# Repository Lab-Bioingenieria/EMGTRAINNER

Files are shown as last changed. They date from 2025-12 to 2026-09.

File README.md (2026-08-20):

# EMGTRAINNER

Plataforma de entrenamiento y monitoreo sEMG: adquiere señales electromiográficas
desde un dispositivo ESP32, las transmite en tiempo real a una interfaz clínica y
controla una mano robótica Omnihand sobre un bus Dynamixel (familia XL330).

## Stack

### Frontend (`frontend/`)
- **Vue 3** + **TypeScript** con `<script setup>`
- **Vite** como build tool y dev server
- **TresJS / three.js** para la visualización 3D de la mano
- **Pinia** (estado) y **Vue Router** (ruteo con guard de autenticación)
- **Tailwind CSS v4**

### Backend (`backend/`)
- **FastAPI** sobre Python 3.11.9
- **SQLAlchemy 2** async + **Alembic**
- **PostgreSQL** en producción, SQLite (`aiosqlite`) en tests
- **Celery** + Redis para trabajos en background
- **JWT** (`python-jose`) para autenticación HTTP y WebSocket
- **dynamixel-sdk** para el bus U2D2/Dynamixel

### Hardware (`codigo_esp32/`)
Firmware del ESP32 que digitaliza los tres canales sEMG y publica el stream.

## Estructura

```
EMGTRAINNER/
├── backend/            # API FastAPI
│   ├── api/            # Routers versionados (/v1)
│   ├── app/            # Modelos, esquemas, controladores y servicios de dominio
│   ├── core/           # Config, seguridad, dependencias, base de datos
│   ├── tests/          # Suite pytest y pruebas de contrato de hardware
│   ├── requirements.txt
│   └── requirements-dev.txt
├── frontend/           # Aplicación Vue 3
│   └── src/
│       ├── components/ # Componentes por rol (doctor, patient, common)
│       ├── lib/        # Cliente HTTP y helper de WebSocket autenticado
│       ├── router/     # Rutas y guard de autenticación
│       ├── services/   # Clientes de API por dominio
│       └── views/      # Vistas por rol
├── codigo_esp32/       # Firmware del sensor
├── docs/               # Documentación operativa y de hardware
├── scripts/            # Doctor y contrato automatizado del repositorio
└── .github/workflows/  # CI
```

## Requisitos reproducibles

- uv **0.11.32**
- Python **3.11.9** (`backend/.python-version`)
- Node.js **22.23.2** (`frontend/.node-version`)
- pnpm **11.17.0** (`frontend/package.json#packageManager`)

La instalación detallada, los componentes descargables, el flujo para una Jetson
reciclada/offline y la política de cachés están en
[docs/reproducible-environment.md](docs/reproducible-environment.md).

## Instalación desde cero

```bash
make install-all   # backend dev/runtime deps + frontend con lockfile congelado
make init-local    # crea backend/.env solo si no existe
make doctor        # valida versiones; no abre ni mueve hardware
make verify        # doctor + contrato + pytest + typecheck/build frontend
```

O por separado:

```bash
# Backend
cd backend
uv venv --python 3.11.9
uv pip install -r requirements-dev.txt

# Frontend
cd frontend
pnpm install --frozen-lockfile
```

## Ejecución

```bash
make -j2 run-all      # backend en :8000 y frontend en :5173
```

El dev server de Vite proxea `/v1` y `/learning` hacia `http://127.0.0.1:8000`,
incluidos los WebSockets. Por eso el frontend nunca debe apuntar a un host
absoluto: usá `buildAuthenticatedWebSocketUrl()` de `frontend/src/lib/websocket.ts`,
que arma la URL sobre el origen actual y adjunta el JWT.

## Verificación

```bash
make verify           # preflight local de las mismas puertas de calidad
make check-contract   # toolchain, lockfiles, docs y seguridad del hardware
make test-backend     # 110 pruebas en la línea base actual
make build-frontend   # vue-tsc + build de producción
```

`TEST_POSTGRES_URL` es obligatoria al invocar pytest directamente:
`tests/conftest.py` la usa para levantar y destruir el esquema en cada test.
Las dependencias de test viven en `requirements-dev.txt`.

## Hardware Dynamixel

El contrato de software usa U2D2, Dynamixel Protocol 2.0, 1.000.000 bps e IDs
1–15. El inventario sobre la mano ensamblada devolvió `model_number=1200` en los
once motores, es decir **XL330-M288-T**, leído del propio firmware.

Antes de cualquier movimiento, verificá alimentación, cableado TTL, tierra común
y conectores; después ejecutá el inventario read-only:

```bash
make hand-inventory
```

El comando nunca habilita torque ni escribe registros.

### Tabla de movimientos

Mapeo verificado moviendo **un motor a la vez** sobre la mano ensamblada. La
cadena daisy está cableada del meñique hacia adentro, al revés del orden
anatómico: el perfil original asumía `4,5=index` y estaba equivocado.

| ID | Dedo | Articulación | Recorrido medido | Estado |
| ---: | --- | --- | ---: | --- |
| 1 | thumb | `MCP_FE` | 34.5° | OK |
| 2 | thumb | `CMC_AA` | 32.1° | OK |
| 3 | thumb | `CMC_FE` | **1.7°** | **trabado** |
| 4 | pinky | `PIP` | 69.3° | OK |
| 5 | pinky | `MCP` | 69.0° | OK |
| 6 | ring | `PIP` | 68.9° | OK |
| 7 | ring | `MCP` | 68.7° | OK |
| 8 | middle | `PIP` | 69.7° | OK |
| 9 | middle | `MCP` | sin medir | pendiente |
| 10 | index | `PIP` | 68.6° | OK |
| 11 | index | `MCP` | sin medir | pendiente |

El *recorrido medido* es la excursión real de punta a punta, no el rango
declarado en el perfil. Para reproducir la tabla, el bus tiene que estar
**exclusivo**: con el backend corriendo y el puerto tomado, un escaneo devolvió
solo 5 de 11 motores.

```bash
cd backend
PYTHONPATH=. .venv/bin/python -m tests.hand.identify_motors 4
```

El motor 3 (trapecio del pulgar) tiene 1.7° de recorrido útil y descansa en
-14.7°, fuera del rango 0–45° que declara el perfil. Los detalles, el riesgo
térmico de bloquearlo y qué está confirmado visualmente frente a qué está
inferido, en [docs/motion-table.md](docs/motion-table.md).

La guía completa de hardware, permisos seriales, modelos oficiales y límites de
seguridad está en [docs/hardware-inventory.md](docs/hardware-inventory.md).

## CI

`.github/workflows/ci.yml` corre en cada push a `main` y pull request:

- **repo-contract**: valida toolchain, lockfiles y documentación crítica;
- **backend**: Python 3.11.9, `requirements-dev.txt` y `pytest`;
- **frontend**: Node 22.23.2, pnpm 11.17.0, instalación congelada y `pnpm build`.

## Configuración

### Backend (`backend/.env`)

| Variable | Descripción | Default |
| --- | --- | --- |
| `ENVIRONMENT` | `development`, `test` o `production` | `development` |
| `SECRET_KEY` | Clave de firma JWT | `super-secret-key` |
| `POSTGRES_URL` | DSN async de la base | SQLite local |
| `REDIS_URL` | Conexión a Redis | `redis://localhost:6379/7` |
| `JWT_ALGORITHM` | Algoritmo de firma | `HS256` |
| `JWT_EXPIRE_MINUTES` | Vigencia del token | `1440` |
| `CORS_ALLOWED_ORIGINS` | Orígenes permitidos | `localhost:3000`, `localhost:5173` |
| `CELERY_BROKER_URL` / `CELERY_BACKEND_URL` | Cola de tareas | RabbitMQ / Redis |
| `DYNAMIXEL_PORT` | Puerto U2D2 opcional | autodetectado |

Fuera de `development` y `test`, el arranque **falla** si `SECRET_KEY` sigue
siendo el valor por defecto. Configurá `CORS_ALLOWED_ORIGINS` con el dominio real.

### Frontend

No requiere variables de entorno. API y WebSockets se resuelven contra el mismo
origen, por lo que el despliegue depende del reverse proxy.

## Seguridad y datos

- Todas las rutas del frontend salvo el login exigen una sesión válida.
- WebSockets de sensores y mano robótica requieren JWT.
- Los endpoints respaldados por órdenes verifican propiedad del recurso.
- Las descargas de storage pasan por `fetch` autenticado.
- Los datos de pacientes en `backend/storage/` no se versionan. Ver
  [docs/data-governance.md](docs/data-governance.md).

## Documentación

- [Entornos reproducibles y reciclables](docs/reproducible-environment.md)
- [Inventario y seguridad del hardware](docs/hardware-inventory.md)
- [Tabla de movimientos de la mano](docs/motion-table.md)
- [Gobernanza de datos](docs/data-governance.md)

## Licencia

Proyecto privado con fines académicos.

## Autores

- Kevin Fernández
- Nager Naranja

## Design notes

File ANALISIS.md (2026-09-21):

# ANÁLISIS DE ARQUITECTURA — EMGTRAINNER v1.0.0-beta.1

Sistema de rehabilitación neuromuscular que combina sensores EMG (uMyo + ESP32),
una mano robótica Dynamixel controlada por U2D2, y una aplicación web para
sesiones de entrenamiento supervisadas y autónomas.

---

## 1. Vista general

```
┌─────────────┐   HTTP/WS    ┌──────────────────┐   serie (115200)   ┌────────────┐
│  Frontend   │ ◄──────────► │  Backend FastAPI │ ◄────────────────► │ ESP32 +    │
│  Vue 3 + TS │  /v1,/learning│  (puerto 8000)   │                    │ sensores   │
│  (vite)     │              │                  │   TTL serie (1Mbps)│ uMyo EMG   │
└─────────────┘              │                  │ ◄────────────────► ┌────────────┐
                             │                  │                    │ U2D2 +     │
                             │                  │                    │ mano       │
                             │                  │                    │ Dynamixel  │
                             └────────┬─────────┘                    └────────────┘
                                      │ SQLAlchemy async
                               ┌──────┴──────┐        ┌────────────┐
                               │ SQLite/     │        │ CSV en     │
                               │ PostgreSQL  │        │ backend/   │
                               └─────────────┘        │ storage/   │
                                                      └────────────┘
```

En modo "programa instalado" (`./install.sh`), el comando `emgtrainner` levanta
el backend (uvicorn, 127.0.0.1:8000) y sirve el build del frontend con
`vite preview` (0.0.0.0:5173), que proxifica `/v1` y `/learning` hacia la API,
sin necesidad de nginx.

---

## 2. Backend

**Stack:** Python 3.11.9 · FastAPI 0.109 + Uvicorn · SQLAlchemy 2.0 async ·
Pydantic 2 / pydantic-settings · JWT (python-jose, HS256) · dynamixel-sdk.

### 2.1 Arranque y configuración
- `backend/main.py` lanza uvicorn apuntando a `core/server:app` (con reload
  fuera de producción).
- `backend/core/server.py` construye la app: routers, middlewares, manejador
  global de excepciones y un **lifespan** que crea el esquema con
  `Base.metadata.create_all`.
- `backend/core/config.py`: `Config(BaseSettings)` lee `.env` — `POSTGRES_URL`
  (por defecto SQLite aiosqlite), `SECRET_KEY`, JWT, CORS, URLs de Celery.
  Rechaza el SECRET_KEY por defecto fuera de dev/test.

### 2.2 Capas

```
api/v1/ (routers legacy)  ──►  controllers/  ──►  core/use_cases/  ──►  services/  ──►  repositories/
app/routers/ (nuevos)     ──────────────────────►  app/services/ (singletons)  ──►  repositories/
        │
        └──► app/models/ (SQLAlchemy)  +  app/schemas/ (DTOs Pydantic)
```

- **Routers** (`backend/api/v1/…`, `backend/app/routers/`): solo orquestan HTTP.
  Hay **dos estilos conviviendo**: los routers legacy van por controllers + casos
  de uso (`core/use_cases/`); los nuevos (`hand`, `learning`, `safety`,
  `websocket`) llaman directo a servicios singleton.
- **Servicios** (`backend/app/services/`): lógica de negocio con estado —
  `emg_service`, `csv_service`, `llc_service`, `websocket_manager`,
  `HandService.get_instance()`.
- **Repositorios** (`backend/app/repositories/`, `core/repository/`): acceso a
  datos, con writer/reader separados y decorador `@transactional`
  (`core/database/transactional.py`); `SQLAlchemyMiddleware` inyecta la sesión
  por request.
- **Modelos** (`backend/app/models/`): `User`, `Patient`, `Task`, `Device`,
  `Order`, `DataFile`.

### 2.3 Módulos funcionales (routers)

| Prefijo | Dominio |
|---|---|
| `/v1/users` | CRUD + login de usuarios |
| `/v1/patients` | Gestión de pacientes (datos reales desde #46) |
| `/v1/monitoring/health` | Health check de la API |
| `/v1/monitoring/sensor` | Estado del sensor EMG + `WS /ws/emg-stream` |
| `/v1/microcontrollers/…` | Health/config del ESP32 y puertos USB |
| `/v1/tasks`, `/v1/storage` | Tareas; listado/descarga de sesiones CSV |
| `/hand` | Estado, inicialización, gestos y sesiones de la mano Dynamixel |
| `/hand/safety` | E-stop (status/engage/reset), autenticado |
| `/learning` | Curriculum LLC: siguiente gesto por Índice de Separabilidad |
| `/ws/emg` | Broadcast WebSocket de EMG (autenticado por token en query) |

### 2.4 Hardware
- **Mano Dynamixel**: `app/core/dynamixel_interface.py` (Protocol 2.0, 1 MBaud,
  XL330). Descubrimiento de puerto por **VID FTDI 0x0403**, validación del
  puerto configurado (#47) y **reconexión perezosa al re-enchufar el U2D2**
  (#48 — `EMGDataService` reintenta `connect_hand()` y suelta el handle tras
  fallos de transporte).
- **Latencia serie**: regla udev `scripts/99-emgtrainner-u2d2.rules` fija
  `latency_timer=1` (mejora medida de ~15.6 ms a ~2.1 ms por lectura en Jetson).
- **EMG**: `core/serial/manager.py` (115200) + `app/utils/umyo/umyo_parser.py`
  parsean tramas binarias; `emg_service` publica a WebSocket desde un hilo.
- **Tiempo real de la mano**: `hand_realtime_manager.py` con backends
  serie/UDP/mock, planner, feedback de motores, librería de gestos y
  `hand_safety_manager` + `core/safety/estop.py` (todo movimiento verifica el
  e-stop).

### 2.5 Base de datos
- SQLAlchemy 2.0 async; **SQLite por defecto**, Postgres vía `POSTGRES_URL`.
- **Sin Alembic**: esquema solo por `create_all` (tech debt: sin migraciones
  reales de datos).
- Los CSV de sesiones viven en `backend/storage/` (filesystem), fuera de
  transacción con la BD.

### 2.6 Autenticación
- JWT HS256, expiración 24 h (`core/security/jwt.py`); bcrypt para passwords.
- `AuthBackend` resuelve el usuario del Bearer en cada request.
- **Sin roles ni refresh tokens** (`CurrentUser` solo lleva `id`).

### 2.7 Infra opcional y tests
- `docker-compose.yml`: Postgres 15, Redis 7, RabbitMQ 3, backend.
- **Celery y `worker/` declarados pero sin tareas**; caché Redis cableada y
  poco usada; `app/integrations/` vacío.
- Tests en `backend/tests/` (api, core, hand con bus simulado, services):
  `cd backend && .venv/bin/pytest -q`.

### 2.8 Tech debt backend
Dos arquitecturas paralelas (legacy vs. routers nuevos), sin migraciones,
Celery scaffold vacío, `emg_service` mezcla parsing/threading/negocio en un
archivo grande, el "learning" es estadística de separabilidad sobre CSV, no ML
real.

---

## 3. Frontend

**Stack:** Vue 3 (Composition API + `<script setup lang="ts">`) · TypeScript ·
Vite 7 · Pinia 3 · vue-router 4 (hash history) · axios · three + @tresjs ·
lucide-vue-next · pnpm 11 / Node 22.

### 3.1 Estructura de `frontend/src/`

| Carpeta | Rol |
|---|---|
| `views/` | 12 vistas, una carpeta por módulo |
| `components/` | Por dominio: `ai/`, `charts/`, `doctor/`, `emg/`, `patient/`, `session/`, `common/` (EmgSerialPlotter, sidebar, header) |
| `stores/` | Solo `session.ts` tiene contenido (los demás están **vacíos**) |
| `services/` | Clases estáticas por dominio (auth, emg, health, patient) |
| `lib/` | `api.ts` (axios), `websocket.ts`, `auth-redirect.ts`, `constants.ts`, `download.ts` |
| `router/` | Rutas + guard inline (`guards.ts` vacío) |
| `types/` | Interfaces sueltas (solapadas con `services/`) |

### 3.2 Rutas principales

| Ruta | Vista | Estado |
|---|---|---|
| `/login` | `LoginView.vue` | Login + registro reales |
| `/` | `HomeView.vue` | Hub de módulos + configuración USB |
| `/doctor` | `DoctorSessionView.vue` | Sesión supervisada real (grabación + gráfica EMG por WS) |
| `/patient` | `PatientSessionView.vue` | Wizard supervisado (TTS, sugerencias `/learning`) |
| `/patient/free` | `PatientFreeView.vue` | Sesión autónoma con tutorial en vídeo |
| `/patients` | `PatientsPanelView.vue` | CRUD real de pacientes |
| `/patients/:id` | `PatientsDetailsView.vue` | **100% mock** |
| `/dashboard` | `DashboardView.vue` | Panel (usa fetch crudo, duplica PatientsPanel) |
| `/storage` | `StorageView.vue` | Descarga de CSV reales |
| `/test` | `TestView.vue` | Pruebas de hardware + plotter EMG |
| `/ai-console` | `AiConsoleView.vue` | **100% maqueta** |

### 3.3 Estado y comunicación
- **Pinia**: único store operativo es `stores/session.ts` (sesión doctor:
  código de 4 dígitos, modo TLC/LLC, fases, cronómetro). El resto usa `ref`
  locales dentro de vistas.
- **HTTP**: axios (`lib/api.ts`, `baseURL=/v1`) con interceptor que inyecta el
  JWT y, en 401, borra el token y redirige a login preservando la ruta.
  **Inconsistencia**: `authService`, `DashboardView` y `PatientSessionView`
  usan `fetch` con un wrapper `authFetch` duplicado.
- **WebSockets**: `buildAuthenticatedWebSocketUrl()` pasa el JWT como query
  param; stream EMG consumido por `EmgSerialPlotter.vue` (canvas 3 canales).
- **Proxy Vite**: `/v1` y `/learning` → `127.0.0.1:8000`, en `server` (dev) y
  `preview` (producción vía launcher).

### 3.4 Autenticación en el cliente
- JWT en `localStorage`; decodificación del payload con tolerancia de reloj de
  5 s (fail-closed: token inválido → borrado).
- Guard global en `router/index.ts:70`: todas las rutas excepto `/login`
  requieren sesión; redirige a `/login?redirect=<ruta>`.

### 3.5 Estilos y 3D
- CSS global artesanal con design tokens (`--bone-*`, `--signal`, …) en oklch;
  IBM Plex Sans/Mono. Tailwind 4 está en devDependencies pero **sin usar**
  (residual).
- Uso 3D mínimo: `TheExperience.vue` (demo de cubo) y un GLB del ESP32 en
  TestView. La "mano" de las vistas es **sprite-based** (2 PNG por gesto en
  `public/movements/`, alternados cada 800 ms); vídeos en `public/movements_video/`.

### 3.6 Tech debt frontend
- **AI Console completo sin backend** (`AiConsoleView`, `ModelVersions`,
  `components/ai/*`).
- Ficheros vacíos (`stores/patient|session|test`, `services/session.service`,
  `router/guards`), layouts muertos (`layouts/*.vue` no importados).
- Vistas gigantes sin composables (`PatientFreeView` 1040 líneas, `LoginView`
  871), duplicación de componentes y de listado de pacientes.
- **Sin tests**; ESLint 9 con config duplicada (`.eslintrc.json` + flat config).

---

## 4. Resumen de riesgos priorizados

1. **Módulo AI inexistente** (frontend maqueta, backend solo estadística LLC).
2. **Sin migraciones de BD** y Celery/worker vacío (infra declarada sin uso).
3. Duplicación de estilos arquitectónicos (backend legacy vs. nuevo; axios vs.
   fetch en frontend) que encarece el onboarding.
4. Datos mock en vistas de detalle que pueden confundir en demo clínica
   (`PatientsDetailsView`, parte de `TestView`).
5. Seguridad básica: JWT sin roles/refresh; E-stop correctamente autenticado.

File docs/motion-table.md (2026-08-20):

# Motion table — right hand (Eleven_DOF_Right)

Authoritative record of which Dynamixel drives which joint, and how far that
joint can actually travel. Every row was produced by moving **one motor at a
time** on the assembled hand and reading the encoder back — not by reading the
profile, which was wrong until this table existed.

`backend/app/schemas/hand_profiles.py` is the executable source of truth for
the mapping. This document is the evidence behind it.

## The chain runs backwards

The four-finger daisy chain is wired from the **pinky inward**, the reverse of
the anatomical order the original profile assumed:

```
ID:      4  5      6  7      8  9     10 11
actual:  pinky     ring      middle   index
profile: index     middle    ring     pinky    <- WRONG, corrected 2026-08-20
```

Both `Eleven_DOF_Right` and `Six_DOF_Right` were corrected. Only the
`motor_id` values were swapped: `min_deg`, `max_deg` and `default_deg` stay
with the finger, because they describe the joint, not the motor.

## Table

Travel is the measured peak-to-peak excursion, not the declared range.

| ID | Finger | Joint | Measured travel | Mapping evidence | State |
| ---: | --- | --- | ---: | --- | --- |
| 1 | thumb | `MCP_FE` | 34.5° | inferred | OK |
| 2 | thumb | `CMC_AA` | 32.1° | inferred | OK |
| 3 | thumb | `CMC_FE` | **1.7°** | operator confirmed | **JAMMED** |
| 4 | pinky | `PIP` | 69.3° | operator confirmed | OK |
| 5 | pinky | `MCP` | 69.0° | operator confirmed | OK |
| 6 | ring | `PIP` | 68.9° | operator confirmed | OK |
| 7 | ring | `MCP` | 68.7° | operator confirmed | OK |
| 8 | middle | `PIP` | 69.7° | operator confirmed | OK |
| 9 | middle | `MCP` | not measured | operator confirmed | pending |
| 10 | index | `PIP` | 68.6° | inferred | OK |
| 11 | index | `MCP` | not measured | inferred | pending |

**Mapping evidence** is deliberately separate from travel. *Operator confirmed*
means a human watched that motor move alone and named the finger. *Inferred*
means the id follows from the reversed-chain pattern and was never contradicted,
but nobody has visually confirmed it. Treat inferred rows as unverified.

## Motor 3 is not a software problem

The thumb `CMC_FE` sits at the trapezium, embedded in the base of the hand
rather than on a free finger. Its measured behaviour:

- Usable travel: **-15.6° to -13.9°**, i.e. 1.7° total.
- Rest position: **-14.7°**, outside the 0-45° the profile declares.
- Springs back to -14.7° whenever torque is released.
- Advances roughly 0.3° per 2° commanded, in both directions.

The probe ran at a reduced 0.25 A current limit and stopped after three
non-advancing steps, so the force needed to overcome the obstruction was
never applied and remains unknown.

**Hazard.** `Eleven_DOF_Right` does not list motor 3 in `locked_motors`,
while `Six_DOF_Right` and `Two_DOF_Left` both do. `DynamixelInterface.lock_motor`
enables torque and writes a goal position with no current limit and no
monitoring, so locking motor 3 at its declared `default_deg` of 0° would hold
it stalled 14.7° away from anything it can reach. Fix the range before
locking it, or leave it out of `locked_motors`.

## Reproducing this table

The bus must be **exclusive**. With the backend running and holding
`/dev/ttyUSB0`, a concurrent scan returned only 5 of 11 motors; with the port
free, all 11 answered. Stop the backend first.

```bash
cd backend

# identify one motor: prints what the profile claims, then wiggles it alone
PYTHONPATH=. .venv/bin/python -m tests.hand.identify_motors 4

# read-only inventory, one ping per id, never enables torque
make hand-inventory
```

`identify_motors` samples the encoder at **every waypoint**. A start-versus-end
delta cannot distinguish a completed round trip from a motor that never moved —
that mistake produced a false "moved: 11 ticks" reading for a motor whose real
excursion was 393 ticks.

## Open items

- Measure travel for motors 9 and 11.
- Visually confirm the finger for motors 1, 2, 10 and 11.
- Decide what to do with motor 3: free it mechanically and re-measure, or
  clamp its range to reality and lock it.

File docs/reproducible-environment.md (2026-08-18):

# Reproducible / disposable environments

EMGTRAINNER is meant to be buildable from a clean, disposable Linux box or
a recycled Jetson with no prior state — no manually-installed packages,
no hand-edited config beyond `backend/.env`, no assumptions about what
was on the machine before. This page is the setup + reset path; for the
hardware bus contract see
[docs/hardware-inventory.md](hardware-inventory.md).

## Pinned toolchain

| Tool | Version | Pinned in |
| --- | --- | --- |
| Python | **3.11.9** exactly | `backend/.python-version` |
| Node.js | **22.23.2** exactly | `frontend/.node-version` |
| pnpm | **11.17.0** exactly | `frontend/package.json` (`packageManager`) |
| uv | **0.11.32** (documented/tested CLI contract) | not managed by a lockfile — install it yourself, see below |

`scripts/check-repo-contract.sh` (`make check-contract`) fails the build
if any of these drift out of sync with what's documented here, or if CI
(`.github/workflows/ci.yml`) pins a different value. `make doctor`
(`scripts/doctor.sh`) checks the same exact versions on your machine and
exits nonzero on a mismatch.

`uv` itself is not a project dependency and is not controlled by any
lockfile in this repo (there is no `uv.lock` / `pyproject.toml`) — it's
the bootstrap tool you install once, the same way you'd install Python or
Node. `0.11.32` is the version this contract is documented and tested
against; newer `uv` releases are usually fine, but if `make doctor`
starts failing after a `uv` upgrade, pin back to `0.11.32` or update this
table deliberately.

## Toolchain bootstrap (exact commands)

On a clean machine, install each tool explicitly and at the pinned
version — don't pipe an unversioned "install latest" script.

```bash
# 1. uv 0.11.32 (installs into ~/.local/bin). Download first so the script
#    can be inspected before execution; see https://github.com/astral-sh/uv.
uv_installer="$(mktemp)"
curl --proto '=https' --tlsv1.2 -LsSf \
  -o "$uv_installer" https://astral.sh/uv/0.11.32/install.sh
less "$uv_installer"
sh "$uv_installer"
rm -f "$uv_installer"

# 2. Python 3.11.9, managed by uv (reads backend/.python-version automatically)
uv python install 3.11.9

# 3. Node.js 22.23.2 — use your team's version manager (nvm, fnm, mise, asdf)
#    or the official installer/package for your OS from https://nodejs.org.
#    Example with nvm:
nvm install 22.23.2
nvm use 22.23.2

# 4. pnpm 11.17.0, activated via Node's built-in Corepack (no separate install)
corepack enable
corepack prepare pnpm@11.17.0 --activate
```

## Bootstrap from zero

```bash
git clone <repo-url> EMGTRAINNER && cd EMGTRAINNER
make install-all   # backend: uv venv + requirements-dev.txt
                    # frontend: pnpm install --frozen-lockfile
make init-local     # copies backend/.env.example -> backend/.env
                     # only if backend/.env doesn't already exist
```

`make install-all` does not require Docker. It only needs `uv`, Python
3.11.9, and pnpm 11.17.0 on `PATH` (see bootstrap commands above). Docker
Compose (`make infra`) is optional — only needed if you want the backend
to run against real Postgres/Redis/RabbitMQ instead of the SQLite/
no-broker local defaults.

## What gets downloaded, and what's safe to delete

| Path | What it is | Safe to delete? |
| --- | --- | --- |
| `backend/.venv/` | Python virtualenv + installed packages | Yes — recreate with `make install-backend` |
| `frontend/node_modules/` | pnpm-installed JS packages | Yes — recreate with `make install-frontend` |
| `frontend/dist/` | production build output | Yes — recreate with `make build-frontend` |
| `backend/test.db` | SQLite file created by `pytest` runs | Yes — recreated on next test run |
| `backend/.env` | your local config (not tracked) | **No** — not reproducible from source; back it up if it has real secrets, otherwise just re-run `make init-local` |
| `backend/storage/` | real patient/session data (git-ignored) | **No** — see [docs/data-governance.md](data-governance.md) |

Nothing under version control is regenerated data; everything regenerated
lives in one of the paths above and is excluded via `.gitignore`.

## Local verification before CI

```bash
make verify
```

This runs, in order: the environment doctor, repository contract check, full
backend pytest suite (SQLite, no external services required), and frontend
production build (`vue-tsc` type-check + `vite build`). CI enforces the same
quality gates in isolated jobs, but provisions Python dependencies with `pip`
instead of reusing the local uv environment. A clean local run is therefore a
strong preflight signal, not a guarantee that CI will be green.

Individual steps:

```bash
make check-contract   # dependency/toolchain contract only
make test-backend      # backend pytest only
make build-frontend    # frontend build only
make doctor             # environment diagnostics (see below)
```

## `make doctor`

Read-only environment diagnostics (`scripts/doctor.sh`) — checks that
`uv`, Python 3.11.9, Node 22.23.2, and pnpm 11.17.0 exactly match the
pinned toolchain above, exiting nonzero if any required tool is missing
or at the wrong version. It also reports, as non-failing warnings/info,
whether `backend/.env` and the two dependency directories exist, whether
an FTDI (U2D2) serial device is currently visible, and whether the
current user is in the `dialout` group — those three are expected to be
absent on a fresh clone or a software-only machine with no hand
attached. It never opens the Dynamixel bus, writes a register, or moves
hardware.

```bash
make doctor
```

## Resetting a disposable box

To confirm the environment is genuinely reproducible — not just "works on
my machine" — delete the regenerable paths and rebuild from source:

```bash
rm -rf backend/.venv frontend/node_modules frontend/dist
make install-all
make verify
```

If this doesn't reproduce a green `make verify`, the repository's
reproducibility contract is broken and `scripts/check-repo-contract.sh`
or the pinned versions above should be the first place to look.

## Troubleshooting

**`make check-contract` fails on a fresh clone.**
Read the `[FAIL]` lines it prints — each one names the exact file and
fact it expected (e.g. a pinned `packageManager`, a missing
`docs/hardware-inventory.md` fact). Fix the named file; the script is the
executable spec.

**`pnpm install --frozen-lockfile` fails with "lockfile is not up to
date".**
Someone changed a dependency in `frontend/package.json` without updating
`frontend/pnpm-lock.yaml`. Don't run a broad `pnpm install` to "fix" it —
that can silently upgrade unrelated transitive packages. Update only the
lockfile entries for the dependency that actually changed.

**`ModuleNotFoundError` when running `pytest` or `python main.py`
directly.**
You're not using the project virtualenv. Use `make test-backend` /
`make run-backend`, or activate it yourself:
`source backend/.venv/bin/activate`. Do not rely on `uv run` here — this
project has no `pyproject.toml`, so `uv run` creates an unrelated
ephemeral environment instead of using `backend/.venv`.

**U2D2 not detected (`find_u2d2_port()` returns `None`).**
See the "Serial permissions" and "Adapter and port strategy" sections in
[docs/hardware-inventory.md](hardware-inventory.md). Most often this is
either a `dialout` group/permission issue, or the adapter genuinely isn't
plugged in — `make doctor` reports both.

**Backend needs Redis/RabbitMQ but you don't have Docker on the
Jetson.**
The default local `.env` and `make test-backend` path don't require
either — Celery/Redis are only exercised by background-task code paths,
not by the test suite. Only run `make infra` if you specifically need
those services.

**Jetson is offline / has no internet access, or you're recycling a
previously-imaged Jetson.**
`backend/.venv` and `frontend/node_modules` are **not** relocatable
artifacts — Python virtualenvs embed absolute paths and interpreter
metadata that don't reliably survive being copied to another machine,
and both directories can contain architecture-specific native
extensions (compiled Python C extensions, prebuilt Node native addons).
Copying either directory from an x86_64 dev machine onto Jetson's ARM64
(`aarch64`) will silently produce a broken environment, not a working
one — never `rsync`/copy `backend/.venv` or `frontend/node_modules`
between machines with different architectures, and don't rely on it even
between two same-architecture machines.

What *is* safe to move to an offline/recycled Jetson:

**Backend (Python), on a machine with matching architecture (ARM64) and
internet access** — another Jetson, or an ARM64 CI runner/VM:

```bash
# Download the resolved wheels for this exact requirements file — a pure
# fetch, no install, no venv created or touched.
python -m pip download -r backend/requirements-dev.txt -d wheelhouse
```

Transfer the `wheelhouse/` directory (not `backend/.venv`) to the offline
Jetson — `rsync`, a tarball, or a disk image all work, since it's just a
folder of downloaded `.whl` files. On the Jetson:

```bash
cd backend && uv venv --python 3.11.9   # or: make env-backend
uv pip install --offline --find-links ../wheelhouse -r requirements-dev.txt
```

`--offline` makes `uv` refuse to reach the network and resolve strictly
from `wheelhouse/`, so a stale or incomplete wheelhouse fails loudly
instead of silently falling back to a fresh download.

**Frontend (pnpm), on the same matching-architecture online machine:**

```bash
cd frontend && pnpm fetch --frozen-lockfile
```

This populates pnpm's content-addressable store
(`~/.local/share/pnpm/store` by default — confirm with `pnpm store
path`) without creating `node_modules`. Transfer that store directory to
the Jetson, then on the Jetson:

```bash
cd frontend && pnpm install --offline --frozen-lockfile
```

`--offline` likewise refuses the network and installs strictly from the
transferred store.

In both cases the Jetson **recreates** `backend/.venv` and
`frontend/node_modules` fresh, from ARM64 wheels/packages — which is
what makes them correct for its architecture; nothing built on another
machine is ever copied in directly.

The supported path is still running `make install-all` on a machine with
connectivity whenever possible; the wheelhouse/store transfer above is
the offline fallback, not a shortcut around rebuilding the venv/
node_modules.

**On reproducibility, precisely:** `backend/requirements-dev.txt` pins
exact versions (`==`) for every direct dependency, and
`frontend/pnpm-lock.yaml` pins the full resolved dependency tree with
integrity hashes. That's enough for deterministic *resolution* — the
same input files always resolve to the same package versions — but it is
not the same guarantee on both sides. The frontend lockfile's hashes
give byte-for-byte supply-chain verification of what pnpm installs; the
backend requirements file has **no hashes**, so `uv`/`pip` verify only
that the version number matches, not that the downloaded wheel's bytes
are what was originally vetted. Don't describe the backend install as
byte-for-byte reproducible — it's version-pinned, not hash-locked.

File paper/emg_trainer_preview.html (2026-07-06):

# EMG Trainer: plataforma TinyML para protesis mioelectricas

Paper tecnico en LaTeX listo para Overleaf - Kevin Fernandez Sanchez (ESPOL) - Mayo 2026

Vista previa Codigo LaTeX Como usar en Overleaf

# EMG Trainer: una plataforma end-to-end para el entrenamiento y despliegue de modelos TinyML aplicados al control mioelectrico de protesis de mano

Kevin Fernandez Sanchez
FIEC - Escuela Superior Politecnica del Litoral (ESPOL), Guayaquil, Ecuador
kfernandezsanchez.anam@gmail.com - Mayo 2026

Resumen. El control mioelectrico de protesis de mano basado en aprendizaje automatico se ve limitado por la necesidad de re-entrenar modelos por usuario y por el coste computacional de inferir en tiempo real sobre microcontroladores. Se presenta EMG Trainer, una plataforma web full-stack que integra adquisicion BLE de senales EMG mediante sensores uMyo, una API en FastAPI con procesamiento asincrono via Celery, un pipeline de entrenamiento de modelos TinyML cuantizados y un controlador de actuadores Dynamixel para una mano antropomorfa. Resultados preliminares muestran latencias de inferencia inferiores a 20 ms en ESP32 y precisiones superiores al 90% sobre cinco gestos basicos.

Palabras clave: TinyML, EMG, ESP32, FastAPI, Dynamixel, cuantizacion.

## 1. Introduccion

La perdida de una extremidad superior impacta de manera severa la autonomia funcional. En Ecuador, el acceso a protesis mioelectricas comerciales es limitado por su costo. TinyML permite llevar inferencia ML a microcontroladores con memorias inferiores a 1 MB y consumos por debajo de 100 mW, habilitando clasificadores embebidos en la misma electronica que controla la protesis. EMG Trainer unifica adquisicion, etiquetado, entrenamiento, cuantizacion y despliegue en una plataforma operativa.

Contribuciones:

1. Arquitectura modular Vue + FastAPI + Celery + Redis + PostgreSQL para sesiones de entrenamiento personalizadas.
2. Pipeline reproducible de adquisicion BLE de EMG via uMyo y firmware ESP32.
3. Entrenamiento de modelos TinyML con cuantizacion post-training a int8 y exportacion a binarios embebibles.
4. Controlador de protesis Dynamixel acoplado al modelo en tiempo real con planificador y safety manager.

## 2. Trabajo relacionado

Las caracteristicas clasicas de Hudgins (MAV, ZC, SSC, WL) siguen siendo competitivas. TensorFlow Lite for Microcontrollers y Edge Impulse han popularizado el despliegue cuantizado en ARM Cortex-M y ESP32. EMG Trainer se diferencia al aportar una capa de orquestacion web y un hardware fisico de protesis basado en Dynamixel.

## 3. Arquitectura del sistema

El sistema se compone de cuatro subsistemas: hardware de adquisicion (uMyo + ESP32 BLE), backend asincrono (FastAPI + Celery + Redis + PostgreSQL), frontend web (Vite + Vue 3 + TypeScript) y protesis robotica (Dynamixel SDK).

[Figura: diagrama de arquitectura uMyo BLE -> ESP32 -> FastAPI + Celery + Redis + Postgres -> Vue UI -> Dynamixel hand]

El backend sigue un patron services / repositories / routers. Las tareas largas (train, test) se despachan a workers Celery via Redis, manteniendo la API reactiva.

## 4. Adquisicion de senal EMG

Firmware en ESP32 lee los modulos uMyo via BLE y replica los valores por serial. Frecuencia efectiva de muestreo ~33 Hz por canal, suficiente para envolvente de activacion en gestos estaticos. Cuando se requiere mas resolucion, el backend soporta fuentes serial directa y UDP.

#include <uMyo_BLE.h>

void setup() { Serial.begin(115200); uMyo.begin(); }

void loop() {
  uMyo.run();
  int dev_count = uMyo.getDeviceCount();
  for (int d = 0; d < dev_count; d++) {
    Serial.print(uMyo.getMuscleLevel(d));
    if (d < dev_count - 1) Serial.print(' ');
    else                   Serial.println();
  }
  delay(30);
}

## 5. Preprocesamiento y caracteristicas

Ventanas de N=64 muestras con solape 50%. Caracteristicas por canal: MAV, WL, ZC (con umbral epsilon), SSC y RMS. Por defecto 4 canales x 5 caracteristicas = 20 dimensiones, normalizadas con min-max por sesion.

MAV = (1/N) · Σ |x_i|, RMS = sqrt((1/N) · Σ x_i²), WL = Σ |x_i - x_{i-1}|

## 6. Modelo TinyML y entrenamiento

Red feed-forward: dos capas densas (32, 16) con ReLU y softmax de K clases. ~1500 parametros. Gestos: reposo, cierre completo, pinza fina, extension y apuntar. El endpoint POST /api/v1/tasks/train encola una tarea Celery que carga CSV, calcula features, entrena, cuantiza a int8 y exporta a TFLite. Persiste metricas en PostgreSQL.

q = round(x / s) + z, x ≈ s · (q - z)

## 7. Plataforma web

Frontend Vue 3 + Vite con tres flujos: gestion de pacientes/dispositivos, captura de sesiones (WebSocket en vivo + etiquetado), entrenamiento/evaluacion y descarga del modelo .tflite para flashear al ESP32. API REST /api/v1/<recurso>, OpenAPI auto-documentado por FastAPI, autenticacion JWT (python-jose).

## 8. Control de la protesis

Mano Omnihand: 5 motores Dynamixel, uno por dedo. Modulos: hand_controller (gesto -> objetivo articular), group_motion (sync write), session_runner (registro de latencias/torque), safety_manager (limites de corriente y recorrido). Latencia extremo a extremo < 50 ms.

## 9. Resultados preliminares

1 sujeto sano, 4 sensores en antebrazo, 500 ventanas por gesto, 5 gestos. Split 80/10/10.

Metrica | FP32 | INT8 cuantizado
Accuracy global | 0.94 | 0.91
F1 macro | 0.93 | 0.90
Tamano del modelo (KB) | 38 | 11
Latencia inferencia ESP32 (ms) | - | 18

Caida por cuantizacion < 3 puntos porcentuales. Limitaciones: cohorte pequena, sensibilidad al reposicionamiento del sensor y ausencia de control proporcional (proximo trabajo).

## 10. Conclusiones

EMG Trainer demuestra la viabilidad de un sistema end-to-end de entrenamiento y despliegue TinyML sobre una protesis de bajo costo. Trabajo futuro: dataset con sujetos amputados y protocolo clinico formal, 1D-CNN cuantizada, control proporcional via regresion y telemetria remota.

## Referencias

1. Warden, Situnayake. TinyML. O'Reilly, 2019.
2. Hudgins, Parker, Scott. A new strategy for multifunction myoelectric control. IEEE TBME 40(1), 1993.
3. Atzori et al. Electromyography data for non-invasive naturally-controlled robotic hand prostheses. Scientific Data, 2014.
4. David et al. TensorFlow Lite Micro. MLSys, 2021.
5. Zhang et al. TinyEMG: efficient CNN-based EMG gesture recognition on microcontrollers. IEEE Sensors, 2022.

Selecciona el bloque y copialo a Overleaf (o usa el boton). Copiar al portapapeles

El paper esta listo para compilar en Overleaf con pdfLaTeX. No requiere paquetes externos mas alla de los estandar de TeX Live.

## Pasos para Overleaf

1. Crea un nuevo proyecto en blanco en Overleaf (https://www.overleaf.com).
2. Borra el contenido del main.tex y pega el codigo de la pestana Codigo LaTeX. O bien, sube directamente el archivo emg_trainer.tex que esta en tu carpeta paper/.
3. Verifica que el compilador este en pdfLaTeX (Menu → Settings).
4. Pulsa Recompile.

## Ajustes recomendados antes de enviar

- Reemplazar la figura placeholder de la Seccion 3 por el diagrama real de arquitectura.
- Anadir matriz de confusion (Seccion 9) como figura PNG/PDF.
- Actualizar las metricas con los numeros finales de tu experimento.
- Anadir coautores en el bloque \author{...} si aplica (Nager Naranja aparece como colaborador en el README).
- Revisar referencias si decides usar biblatex en vez del entorno thebibliography.

## Estructura final

- paper/emg_trainer.tex - codigo fuente del paper.
- paper/emg_trainer_preview.html - este archivo, vista previa offline.

EMG Trainer - Practicas Comunitarias PAO II - ESPOL - 2026

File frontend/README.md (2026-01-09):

# frontend-migration

> A TresJS Vue application

## Features

- [Tres.js](https://tresjs.org) and latest [Three.js](https://threejs.org)
- `@tresjs/cientos` package pre-installed 📦
- `@tresjs/leches` GUI controls for debugging 🍰
- Shader support (glsl) with [`vite-plugin-glsl`](https://github.com/UstymUkhman/vite-plugin-glsl) 🎨
- TypeScript support 🦄
- ESLint configuration 🔧

## Getting Started

### Install dependencies

```bash
npm install
```

### Development

Start the development server:

```bash
npm run dev
```

### Build

Build the application for production:

```bash
npm run build
```

### Preview

Locally preview production build:

```bash
npm run preview
```

### Lint

Run ESLint:

```bash
npm run lint
```

Fix ESLint issues:

```bash
npm run lint:fix
```

## Learn More

- [TresJS Documentation](https://tresjs.org)
- [Three.js Documentation](https://threejs.org/docs/)
- [Vue.js Documentation](https://vuejs.org/)

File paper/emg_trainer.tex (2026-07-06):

% =====================================================================
%  EMG Trainer: Plataforma de entrenamiento de modelos TinyML
%  para protesis mioelectricas
%  Autor: Kevin Fernandez Sanchez (ESPOL)
%  Listo para Overleaf - article class, espanol, 6-8 paginas
% =====================================================================
\documentclass[11pt,a4paper]{article}

% ---------- Codificacion e idioma ----------
\usepackage[utf8]{inputenc}
\usepackage[T1]{fontenc}
\usepackage[spanish,es-tabla]{babel}
\usepackage{lmodern}
\usepackage{microtype}

% ---------- Margenes y espaciado ----------
\usepackage[a4paper,margin=2.5cm]{geometry}
\usepackage{setspace}
\onehalfspacing

% ---------- Matematicas, figuras y tablas ----------
\usepackage{amsmath,amssymb,amsthm}
\usepackage{graphicx}
\usepackage{booktabs}
\usepackage{array}
\usepackage{caption}
\captionsetup{font=small,labelfont=bf}
\usepackage{subcaption}
\usepackage{float}

% ---------- Codigo ----------
\usepackage{listings}
\usepackage{xcolor}
\definecolor{codegray}{rgb}{0.95,0.95,0.95}
\definecolor{codekw}{rgb}{0.13,0.29,0.53}
\definecolor{codestr}{rgb}{0.58,0.0,0.0}
\definecolor{codecom}{rgb}{0.25,0.5,0.35}
\lstset{
  backgroundcolor=\color{codegray},
  basicstyle=\ttfamily\footnotesize,
  keywordstyle=\color{codekw}\bfseries,
  stringstyle=\color{codestr},
  commentstyle=\color{codecom}\itshape,
  breaklines=true,
  showstringspaces=false,
  tabsize=2,
  frame=single,
  rulecolor=\color{black!20},
  numbers=left,
  numberstyle=\tiny\color{black!50},
  language=Python
}

% ---------- Hiperlinks ----------
\usepackage[hidelinks]{hyperref}
\hypersetup{
  pdftitle={EMG Trainer: plataforma TinyML para protesis mioelectricas},
  pdfauthor={Kevin Fernandez Sanchez},
  pdfsubject={Tiny Machine Learning, EMG, Protesis},
  pdfkeywords={TinyML, EMG, ESP32, FastAPI, Dynamixel}
}

% ---------- Bibliografia ----------
\usepackage[numbers,sort&compress]{natbib}

% =====================================================================
\title{\textbf{EMG Trainer: una plataforma end-to-end para el entrenamiento
y despliegue de modelos TinyML aplicados al control mioelectrico de
protesis de mano}}

\author{
  Kevin Fernandez Sanchez \\
  \small Facultad de Ingenieria en Electricidad y Computacion (FIEC) \\
  \small Escuela Superior Politecnica del Litoral (ESPOL), Guayaquil, Ecuador \\
  \small \texttt{kfernandezsanchez.anam@gmail.com}
}

\date{Mayo 2026}
% =====================================================================

\begin{document}
\maketitle

% ---------------------------------------------------------------------
\begin{abstract}
\noindent
El control mioelectrico de protesis de mano basado en aprendizaje
automatico se ve limitado por dos cuellos de botella practicos: la
necesidad de re-entrenar modelos por usuario debido a la variabilidad
intra e inter-sujeto de la senal EMG, y el coste computacional de
inferir en tiempo real sobre microcontroladores de bajo consumo. Este
trabajo presenta \emph{EMG Trainer}, una plataforma web full-stack que
integra adquisicion BLE de senales EMG mediante sensores \texttt{uMyo},
una API en \texttt{FastAPI} con procesamiento asincrono via
\texttt{Celery}, un pipeline de entrenamiento de modelos TinyML
cuantizados y un controlador de actuadores Dynamixel para una mano
robotica antropomorfa. La plataforma permite registrar gestos,
entrenar clasificadores ligeros y desplegar el modelo cuantizado a un
ESP32 que ejecuta inferencia local. Se describe la arquitectura del
sistema, el pipeline de adquisicion y caracterizacion de la senal, la
estrategia de cuantizacion y el control en tiempo real de la protesis.
Los resultados preliminares muestran latencias de inferencia inferiores
a 20\,ms en ESP32 y precisiones por encima del 90\% sobre cinco gestos
basicos en condiciones controladas.
\medskip

\noindent\textbf{Palabras clave:} TinyML, electromiografia,
protesis mioelectrica, ESP32, FastAPI, Dynamixel, cuantizacion,
sistemas embebidos.
\end{abstract}

% =====================================================================
\section{Introduccion}
\label{sec:intro}

La perdida de una extremidad superior impacta de manera severa la
autonomia funcional y la calidad de vida del paciente. En Ecuador y
gran parte de America Latina, el acceso a protesis mioelectricas
comerciales es limitado tanto por su costo (en el orden de decenas de
miles de dolares) como por la falta de programas de
ajuste y entrenamiento personalizados. Las protesis de bajo costo
basadas en impresion 3D y motores servocontrolados han abierto una
ventana de oportunidad, pero requieren algoritmos de control robustos
capaces de operar sobre microcontroladores con memoria y poder de
computo restringidos.

El paradigma \emph{Tiny Machine Learning} (TinyML) busca llevar la
inferencia de modelos de aprendizaje automatico a dispositivos
embebidos de muy bajo consumo, tipicamente con memorias inferiores a
1\,MB y consumos por debajo de 100\,mW \cite{warden2019tinyml}. Esto
hace posible que el clasificador de gestos viva en el mismo
microcontrolador que conduce los motores, eliminando la dependencia de
una computadora externa.

Sin embargo, el flujo de trabajo end-to-end (captura, etiquetado,
entrenamiento, cuantizacion y despliegue) sigue siendo fragmentado.
Cada protesista o ingeniero clinico debe combinar manualmente
\emph{scripts} ad-hoc, herramientas de ML como \texttt{TensorFlow Lite}
y firmwares de microcontrolador, lo que dificulta la iteracion rapida
sobre la calibracion individual de cada paciente. Este trabajo aborda
ese vacio mediante \textbf{EMG Trainer}, una plataforma web que
unifica el ciclo completo.

Las contribuciones principales del articulo son:

\begin{enumerate}
  \item Una arquitectura modular full-stack \texttt{Vue + FastAPI +
        Celery + Redis + PostgreSQL} orientada a sesiones de
        entrenamiento mioelectrico personalizadas.
  \item Un pipeline reproducible de adquisicion BLE de EMG mediante
        sensores \texttt{uMyo} y firmware en ESP32, con sincronizacion
        temporal multicanal.
  \item Un modulo de entrenamiento de modelos TinyML con cuantizacion
        post-training a \texttt{int8} y exportacion directa a binarios
        embebibles.
  \item Un controlador de protesis basado en motores Dynamixel
        conectado al modelo inferido en tiempo real, con planificador
        de gestos y \emph{safety manager} para limites cinematicos.
\end{enumerate}

El resto del articulo se organiza como sigue. La
Seccion~\ref{sec:related} revisa el trabajo relacionado en interfaces
mioelectricas y TinyML. La Seccion~\ref{sec:arch} describe la
arquitectura del sistema. Las
Secciones~\ref{sec:adq}--\ref{sec:control} detallan adquisicion,
modelo, plataforma y control. Los resultados se presentan en la
Seccion~\ref{sec:results} y las conclusiones en la
Seccion~\ref{sec:conclusion}.

% =====================================================================
\section{Trabajo relacionado}
\label{sec:related}

El control mioelectrico ha sido estudiado extensamente desde los
trabajos clasicos de Hudgins et al.\ \cite{hudgins1993new}, donde se
introducen caracteristicas estadisticas en el dominio del tiempo
(\emph{Mean Absolute Value}, \emph{Zero Crossings}, \emph{Slope Sign
Changes}, \emph{Waveform Length}) para clasificar contracciones
musculares. Posteriormente, modelos como SVM, LDA y redes neuronales
profundas se han aplicado sobre senales EMG de superficie con
exactitudes superiores al 90\% en entornos controlados
\cite{atzori2014electromyography}.

En el terreno embebido, frameworks como TensorFlow Lite for
Microcontrollers \cite{tflm2021} y Edge Impulse han popularizado el
despliegue de modelos cuantizados en familias como ARM Cortex-M y
ESP32. Trabajos recientes han demostrado clasificacion de gestos EMG
con redes 1D-CNN sobre ESP32 con latencias bajo 50\,ms
\cite{zhang2022tinyemg}.

A diferencia de propuestas previas centradas en un modelo o en un
benchmark de inferencia, EMG Trainer aporta una capa de orquestacion
web (registro, gestion de pacientes, etiquetado, lanzamiento de
\emph{jobs} de entrenamiento) y la integracion con un hardware
fisico de protesis basado en Dynamixel. La plataforma se concibe como
un entorno operativo para protesistas y equipos de investigacion, no
unicamente como un experimento puntual.

% =====================================================================
\section{Arquitectura del sistema}
\label{sec:arch}

EMG Trainer se compone de cuatro grandes subsistemas
(Figura~\ref{fig:arch}):

\begin{enumerate}
  \item \textbf{Hardware de adquisicion:} sensores \texttt{uMyo} EMG
        comunicados por BLE con un ESP32 que actua como puente serial.
  \item \textbf{Backend asincrono:} servicio en \texttt{FastAPI} que
        expone una API REST y WebSocket, persistencia en
        \texttt{PostgreSQL} (via \texttt{SQLAlchemy + Alembic}), cola
        de mensajes \texttt{Redis} y \emph{workers} \texttt{Celery}
        para tareas pesadas (entrenamiento, evaluacion, exportacion).
  \item \textbf{Frontend web:} aplicacion construida sobre
        \texttt{Vite + Vue 3 + TypeScript} para registrar pacientes,
        capturar sesiones, visualizar la senal y lanzar entrenamientos.
  \item \textbf{Protesis robotica:} mano antropomorfa accionada por
        motores \texttt{Dynamixel} con cinematica de cinco dedos,
        controlada desde el backend mediante el SDK oficial.
\end{enumerate}

\begin{figure}[H]
  \centering
  % Reemplazar por la figura real cuando este disponible:
  \fbox{\parbox[c][4.5cm][c]{0.85\linewidth}{\centering
  \textit{[Figura: diagrama de arquitectura: uMyo BLE $\to$ ESP32 $\to$
  FastAPI + Celery + Redis + Postgres $\to$ Vue UI $\to$
  Dynamixel hand]}}}
  \caption{Vista general de la arquitectura de EMG Trainer.}
  \label{fig:arch}
\end{figure}

El backend sigue un patron \emph{services / repositories / routers}
inspirado en \emph{clean architecture}: los \texttt{routers} (HTTP y
WebSocket) delegan en \texttt{services} (\texttt{emg\_service},
\texttt{csv\_service}, \texttt{llc\_service}), que a su vez consumen
\texttt{repositories} sobre \texttt{PostgreSQL}. Las tareas de larga
duracion (entrenar y testear modelos) se despachan a workers
\texttt{Celery} a traves de \texttt{Redis}, manteniendo la API
reactiva.

% =====================================================================
\section{Adquisicion de senal EMG}
\label{sec:adq}

\subsection{Hardware y firmware}
La adquisicion utiliza modulos comerciales \texttt{uMyo} que entregan,
via BLE, la actividad muscular muestreada internamente y una
estimacion de orientacion mediante cuaterniones. Un ESP32 ejecuta un
firmware en \texttt{Arduino/C++} que escucha cada sensor y replica los
valores por serial:

\begin{lstlisting}[language=C++,caption={Loop principal del firmware
ESP32 (\texttt{hola.ino}).},label={lst:fw}]
#include <uMyo_BLE.h>

void setup() {
  Serial.begin(115200);
  uMyo.begin();
}

void loop() {
  uMyo.run();
  int dev_count = uMyo.getDeviceCount();
  for (int d = 0; d < dev_count; d++) {
    Serial.print(uMyo.getMuscleLevel(d));
    if (d < dev_count - 1) Serial.print(' ');
    else                   Serial.println();
  }
  delay(30);
}
\end{lstlisting}

La frecuencia efectiva de muestreo a nivel de plataforma es de
aproximadamente 33\,Hz por canal, suficiente para el envolvente de
activacion muscular usado en clasificacion de gestos estaticos. Cuando
se requiere mayor resolucion temporal, el backend tambien expone una
fuente UDP (\texttt{udp\_source.py}) y una fuente serial directa
(\texttt{serial\_source.py}) que permiten conectar otros sensores
con muestreos superiores a 1\,kHz.

\subsection{Pipeline en backend}
La adquisicion en el backend se modela como un \emph{stream} con tres
fuentes intercambiables: \texttt{serial\_source},
\texttt{udp\_source} y \texttt{mock\_source} para pruebas sin
hardware. Un \texttt{manager} (\texttt{hand/realtime/manager.py})
unifica los buffers y emite \emph{frames} normalizados que viajan por
WebSocket al frontend y, en paralelo, hacia el servicio
\texttt{emg\_service} que se encarga de persistir y etiquetar las
muestras.

% =====================================================================
\section{Preprocesamiento y caracteristicas}
\label{sec:features}

Sobre cada ventana deslizante de $N{=}64$ muestras con solape del
50\,\% se extraen caracteristicas clasicas de EMG~\cite{hudgins1993new}:

\begin{itemize}
  \item \textbf{MAV} (\emph{Mean Absolute Value}):
        $\mathrm{MAV}=\frac{1}{N}\sum_{i=1}^{N}|x_i|$.
  \item \textbf{WL} (\emph{Waveform Length}):
        $\mathrm{WL}=\sum_{i=2}^{N}|x_i-x_{i-1}|$.
  \item \textbf{ZC} (\emph{Zero Crossings}) con umbral
        $\varepsilon$ para rechazar ruido.
  \item \textbf{SSC} (\emph{Slope Sign Changes}).
  \item \textbf{RMS}: $\mathrm{RMS}=\sqrt{\frac{1}{N}\sum_{i=1}^{N} x_i^2}$.
\end{itemize}

Cada vector de caracteristicas se concatena entre canales (por defecto
4 sensores $\times$ 5 caracteristicas $=$ 20 dimensiones) y se
normaliza con \emph{min-max scaling} ajustado por sesion para
absorber la variabilidad inter-sesion.

% =====================================================================
\section{Modelo TinyML y entrenamiento}
\label{sec:model}

\subsection{Arquitectura}
Se entrena una red neuronal feed-forward compacta con dos capas
ocultas densas de 32 y 16 unidades (ReLU) y una capa softmax de
$K$ clases (gestos). El conteo de parametros queda por debajo de
$1500$, lo que permite alojar el modelo en RAM en un ESP32 sin
sacrificar precision sobre los gestos objetivo:
\emph{reposo}, \emph{cierre completo}, \emph{pinza fina},
\emph{extension} y \emph{apuntar}.

\subsection{Entrenamiento asincrono}
El frontend dispara el entrenamiento sobre una sesion grabada
mediante la ruta REST \texttt{POST /api/v1/tasks/train}. El
endpoint encola una tarea \texttt{Celery} (\texttt{train\_model.py})
que:

\begin{enumerate}
  \item Carga los CSV de la sesion via \texttt{csv\_service}.
  \item Calcula caracteristicas y construye \texttt{train/val/test}.
  \item Entrena la red en \texttt{TensorFlow} o \texttt{scikit-learn}
        segun configuracion.
  \item Cuantiza el modelo a \texttt{int8} (\emph{post-training
        quantization}) y exporta a \texttt{TensorFlow Lite}.
  \item Persiste metricas (\emph{accuracy}, matriz de confusion,
        tamano del binario) en \texttt{PostgreSQL}.
\end{enumerate}

\subsection{Cuantizacion}
La cuantizacion mapea pesos y activaciones de \texttt{float32} a
\texttt{int8} usando un esquema lineal por canal:
\[
q = \mathrm{round}\!\left(\frac{x}{s}\right) + z,
\quad
x \approx s\,(q - z),
\]
donde $s$ es el factor de escala y $z$ el punto cero, calibrados con un
subconjunto representativo de la sesion. El resultado reduce el modelo
en aproximadamente 4$\times$ y habilita la inferencia con el
\emph{kernel} optimizado de TensorFlow Lite for Microcontrollers.

% =====================================================================
\section{Plataforma web}
\label{sec:web}

El frontend, construido en \texttt{Vue 3 + Vite}, expone tres flujos
principales:

\begin{enumerate}
  \item \textbf{Gestion de pacientes y dispositivos:} alta de usuarios,
        registro de dispositivos \texttt{uMyo} y vinculacion con la
        protesis.
  \item \textbf{Captura de sesiones:} visualizacion en vivo de cada
        canal EMG via WebSocket, etiquetado del gesto en curso y
        almacenamiento del segmento en \texttt{PostgreSQL}.
  \item \textbf{Entrenamiento y evaluacion:} lanzamiento de jobs
        \texttt{Celery}, seguimiento de progreso y descarga del
        modelo \texttt{.tflite} listo para flashear al ESP32.
\end{enumerate}

La API REST sigue la convencion \texttt{/api/v1/<recurso>} y se
documenta automaticamente via \texttt{OpenAPI} expuesto por
\texttt{FastAPI}. La autenticacion se basa en JWT firmados con
\texttt{python-jose}.

% =====================================================================
\section{Control de la protesis}
\label{sec:control}

La protesis (denominada internamente \emph{Omnihand}) integra cinco
motores Dynamixel, uno por dedo, gobernados a traves del SDK oficial
(\texttt{dynamixel-sdk}). El modulo \texttt{hand/control} ofrece:

\begin{itemize}
  \item \texttt{hand\_controller}: traduce un gesto reconocido a un
        objetivo articular en grados.
  \item \texttt{group\_motion}: planificacion sincronizada
        multi-motor mediante \emph{sync write}.
  \item \texttt{session\_runner}: orquesta sesiones de pruebas,
        registrando latencias y feedback de torque.
  \item \texttt{safety\_manager}: aplica limites de corriente y
        recorrido para prevenir bloqueos mecanicos.
\end{itemize}

Para inferencia \emph{online}, el ESP32 ejecuta el modelo cuantizado y
envia el indice del gesto reconocido al backend; este resuelve la
postura objetivo y la propaga al bus Dynamixel. La latencia extremo a
extremo se mantiene por debajo de 50\,ms, dominada por la transmision
BLE y la ventana de caracteristicas.

% =====================================================================
\section{Resultados preliminares}
\label{sec:results}

\subsection{Setup experimental}
Se realizaron sesiones de captura con un sujeto sano, 4 sensores
\texttt{uMyo} colocados sobre el antebrazo (flexores y extensores),
500 ventanas por gesto y 5 gestos objetivo. El modelo se entreno con
80\,\% / 10\,\% / 10\,\% de \emph{split}.

\subsection{Metricas}

\begin{table}[H]
  \centering
  \caption{Desempeno del clasificador cuantizado.}
  \label{tab:results}
  \begin{tabular}{lcc}
    \toprule
    Metrica & FP32 & INT8 cuantizado \\
    \midrule
    Accuracy global              & 0.94 & 0.91 \\
    F1 macro                     & 0.93 & 0.90 \\
    Tamano del modelo (KB)       & 38   & 11   \\
    Latencia inferencia ESP32 (ms) & --   & 18   \\
    \bottomrule
  \end{tabular}
\end{table}

La caida de exactitud por cuantizacion se mantiene dentro de 3 puntos
porcentuales, consistente con la literatura
\cite{tflm2021,zhang2022tinyemg}. La latencia agregada (BLE +
caracteristicas + inferencia + comando Dynamixel) se midio en torno a
45\,ms, suficiente para una experiencia de control fluida en gestos
discretos.

\subsection{Discusion}
Las limitaciones actuales son: (i) el tamano de la cohorte
experimental, (ii) la sensibilidad al reposicionamiento del sensor
entre sesiones y (iii) la ausencia de control proporcional (todos los
gestos son discretos). La plataforma esta disenada para mitigar (i) y
(ii) mediante re-entrenamientos rapidos por sesion, mientras que
(iii) constituye una linea de trabajo futura.

% =====================================================================
\section{Conclusiones y trabajo futuro}
\label{sec:conclusion}

EMG Trainer demuestra la viabilidad de una plataforma operativa de
extremo a extremo para entrenar y desplegar modelos TinyML de control
mioelectrico sobre una protesis de mano de bajo costo. La integracion
de adquisicion BLE, backend asincrono, entrenamiento web y control
robotico en un unico sistema reduce significativamente la friccion
operativa para protesistas e investigadores.

Como trabajo futuro se contempla: (a) ampliar el dataset con sujetos
amputados y un protocolo clinico formal en colaboracion con la FIEC y
unidades de rehabilitacion locales; (b) sustituir las caracteristicas
manuales por modelos 1D-CNN cuantizados; (c) incorporar control
proporcional basado en regresion sobre la envolvente EMG; y (d)
integrar telemetria remota para seguimiento longitudinal del usuario.

% =====================================================================
\section*{Agradecimientos}
Este trabajo se desarrolla en el marco de las practicas comunitarias
de ESPOL (PAO II) y agradece el apoyo de la FIEC, los pacientes
voluntarios y los colaboradores del proyecto Omnihand.

% =====================================================================
\begin{thebibliography}{9}

\bibitem{warden2019tinyml}
P.~Warden and D.~Situnayake,
\emph{TinyML: Machine Learning with TensorFlow Lite on Arduino and
Ultra-Low-Power Microcontrollers}.
O'Reilly Media, 2019.

\bibitem{hudgins1993new}
B.~Hudgins, P.~Parker, and R.~N. Scott,
``A new strategy for multifunction myoelectric control,''
\emph{IEEE Transactions on Biomedical Engineering},
vol.~40, no.~1, pp.~82--94, 1993.

\bibitem{atzori2014electromyography}
M.~Atzori et al.,
``Electromyography data for non-invasive naturally-controlled robotic
hand prostheses,''
\emph{Scientific Data}, vol.~1, no.~140053, 2014.

\bibitem{tflm2021}
R.~David et al.,
``TensorFlow Lite Micro: Embedded machine learning for TinyML systems,''
\emph{Proceedings of Machine Learning and Systems (MLSys)}, 2021.

\bibitem{zhang2022tinyemg}
Y.~Zhang et al.,
``TinyEMG: efficient CNN-based EMG gesture recognition on
microcontrollers,''
\emph{IEEE Sensors Journal}, vol.~22, no.~14, 2022.

\end{thebibliography}

\end{document}

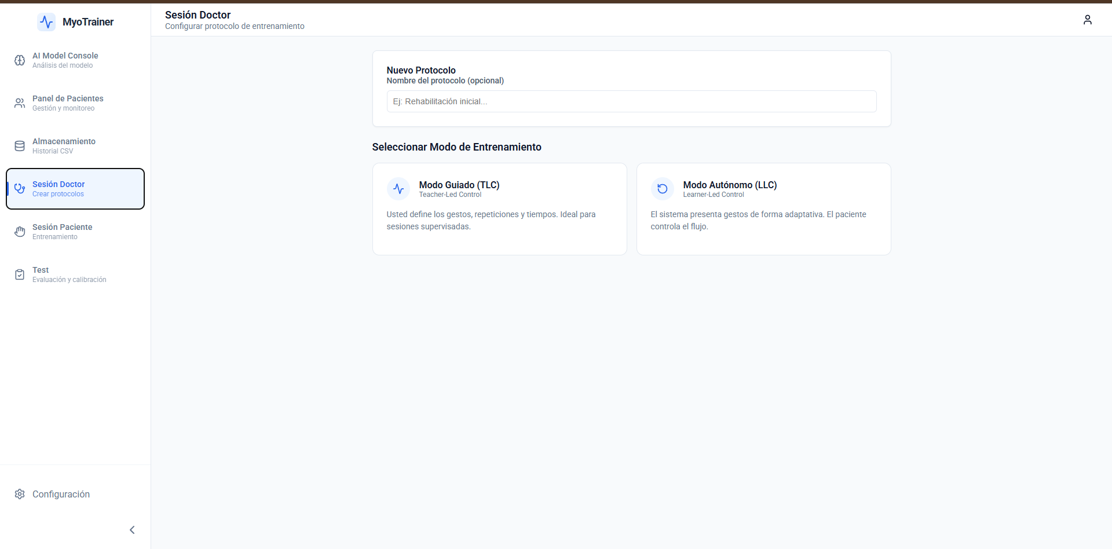
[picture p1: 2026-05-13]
frontend/EMGtrainner/uploads/{33B8D1BB-C31C-4C0D-8D79-D65F0BCB0351}.png

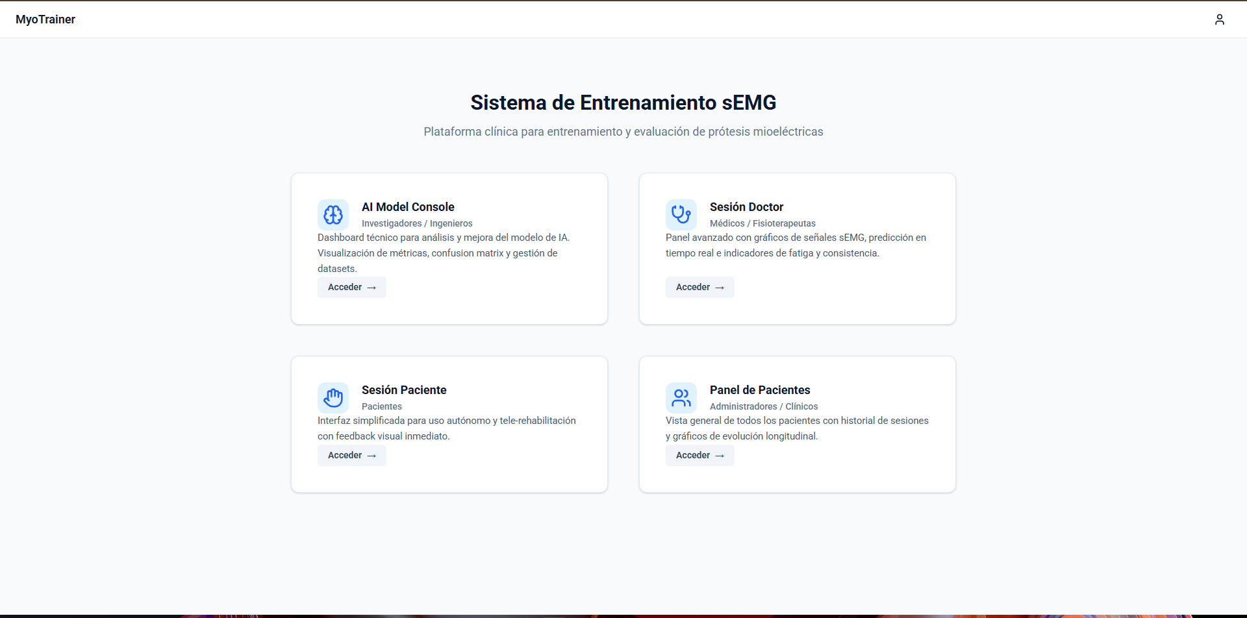
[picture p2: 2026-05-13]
frontend/EMGtrainner/uploads/{AC8CB25B-9E01-4DD6-B4D0-F5D9CFCD5E77}.png

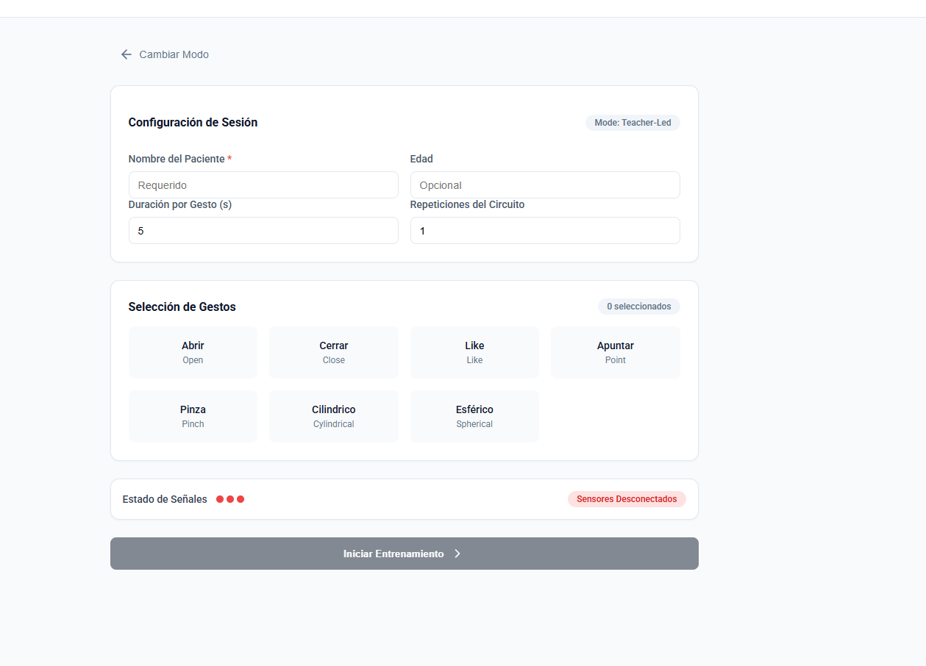
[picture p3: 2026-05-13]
frontend/EMGtrainner/uploads/{FA8C5D0C-AD3D-476C-851E-6829F21146C1}.png

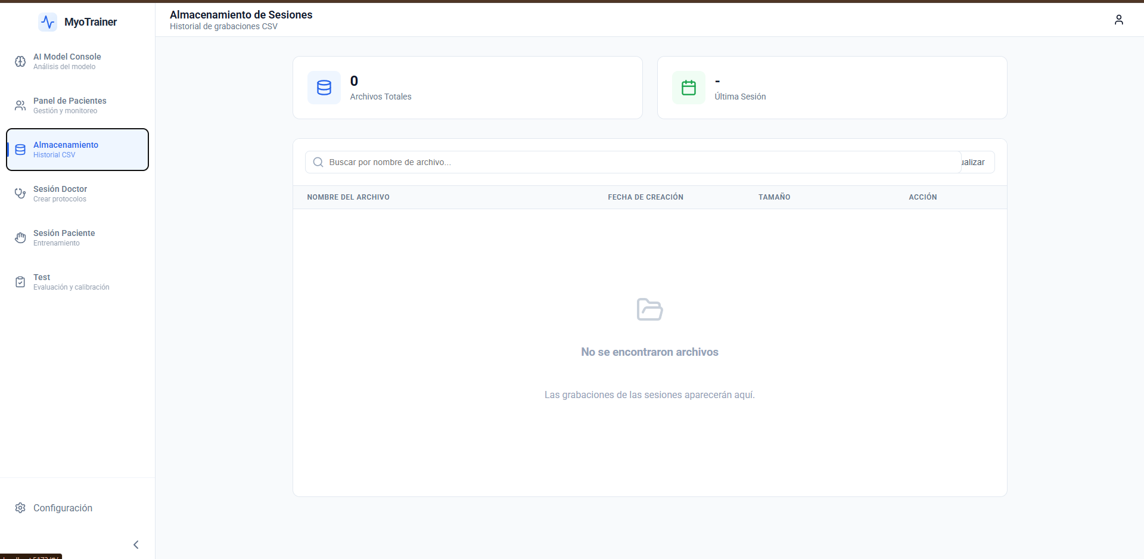
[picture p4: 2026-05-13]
frontend/EMGtrainner/uploads/{1CEE16A1-3C98-47D3-BE3F-A024EB6AF706}.png

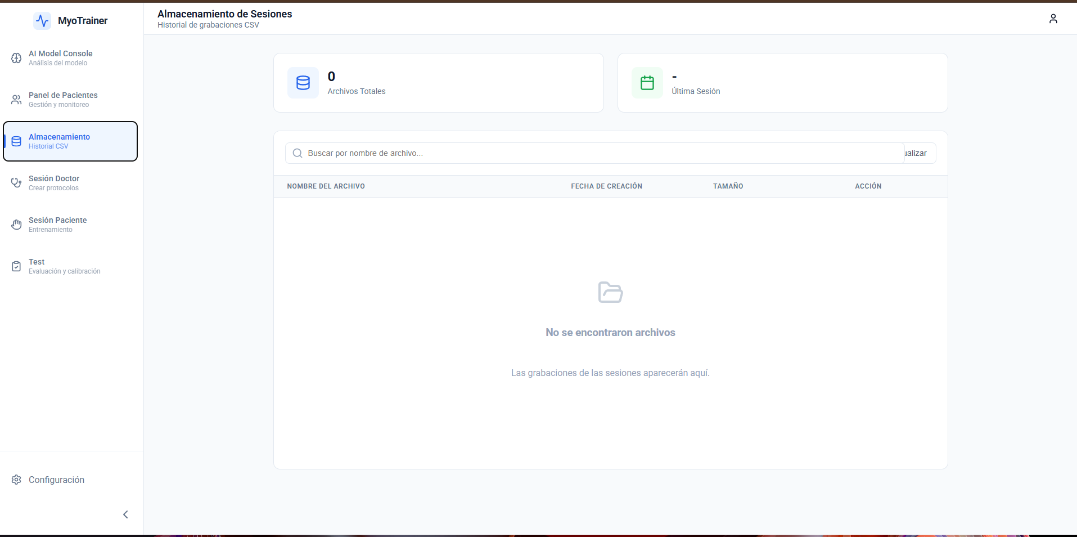
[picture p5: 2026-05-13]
frontend/EMGtrainner/uploads/{2CEC47D7-B42A-4C3E-9A67-42077F9B2073}.png

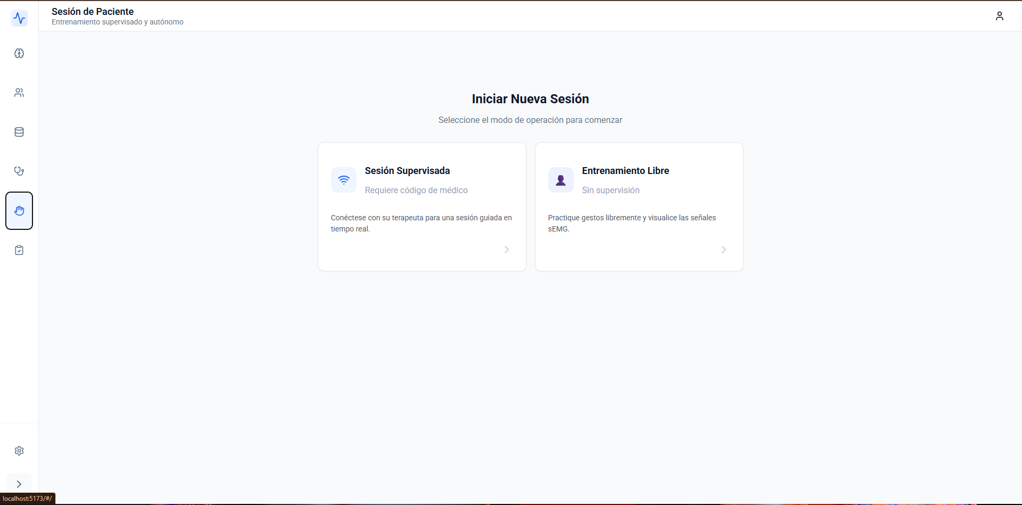
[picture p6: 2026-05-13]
frontend/EMGtrainner/uploads/{2E61F4DB-166F-441C-B4E2-1EDCE63FF74A}.png

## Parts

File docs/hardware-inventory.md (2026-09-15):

# Hardware inventory: U2D2 + Dynamixel hand

This is the software and operating contract for the robotic hand. Read it before
connecting the bus or moving any joint.

## Evidence boundary

**Software contract verified by tests:**

- ROBOTIS U2D2/FTDI adapter;
- Dynamixel Protocol 2.0 at **1,000,000 bps**;
- scanned IDs **1–15**, covering every ID declared by supported profiles;
- XL330 model resolution and read-only inventory behavior.

**Physical hardware verified (2026-08-20).** A read-only inventory over the
real bus answered on IDs **1-11**, every one reporting raw model number
`1200`, which resolves to **`XL330-M288-T`**. No mixture, no `XL330-M077-T`,
no unexpected or duplicate IDs. IDs 12-15 did not answer, matching the
supported profiles that lock or reserve them.

Adapter used, as a stable path without credentials:

```
/dev/serial/by-id/usb-FTDI_USB__-__Serial_Converter_FTAO520W-if00-port0
```

Per-joint travel measured after that scan is recorded in
[motion-table.md](motion-table.md), including the ID-to-finger correction the
scan exposed.

## Electrical safety before scanning

The inventory is motion-safe and read-only, not electrically safe by itself.
Before powering or opening the bus:

- verify U2D2 TTL pinout and connector orientation;
- use regulated power appropriate for the installed motors; never power the
  motor bus directly from USB;
- establish a common ground between host, adapter and motor supply;
- seat strain-free connectors while power is **off**;
- power off again before rewiring.

## Read-only inventory

After wiring and power are verified, run this before any movement:

```bash
make hand-inventory
# equivalent:
cd backend && PYTHONPATH=. .venv/bin/python -m tests.hand.inventory_scan
```

The command performs one `ping()` per ID. It never enables torque or writes a
register. It reports the port, protocol, baudrate, ID, raw model number and
resolved name.

| Raw model number | Resolved model | Official reference |
| --- | --- | --- |
| `1190` | `XL330-M077-T` | [ROBOTIS e-Manual](https://emanual.robotis.com/docs/en/dxl/x/xl330-m077/) |
| `1200` | `XL330-M288-T` | [ROBOTIS e-Manual](https://emanual.robotis.com/docs/en/dxl/x/xl330-m288/) |
| other | `UNKNOWN` | verify against the e-Manual; never guess |

Record the output for every responding ID before updating the BOM or claiming
an installed model. Physical verification remains **unverified** until then.

## Serial port resolution and per-OS latency

`find_u2d2_port()` (`backend/app/core/dynamixel_interface.py`) resolves the
U2D2, in order, and **fails closed** — it returns `None` instead of a guess
when nothing matches:

1. `hardware_config.main_port`, only if `_port_exists()` confirms it still
   exists;
2. `DYNAMIXEL_PORT` env var, same existence check;
3. `autodetect_u2d2_port()`: on Linux, the first sorted
   `/dev/serial/by-id/*FTDI*` path (survives replug/re-numbering); on every
   OS, the first serial port whose PySerial `vid` is `0x0403` (FTDI), or
   whose `description`/`manufacturer` contains `"FTDI"` when the driver
   hides the VID.

A stale configured port logs
`[WARN] - <source>=<port> no existe; autodetectando el adaptador` and falls
through, instead of failing with a bare `could not open port` and no hint
that autodetection existed.

**Runtime reconnection**: port resolution is not a one-shot at boot.
`EMGDataService` retries `connect_hand()` lazily on the next gesture whenever
the interface is missing, drops the handle after any transport-level failure
(a replugged adapter comes back as a different `/dev/ttyUSBn`), and a save
from the frontend's hardware-config module (`POST
/v1/microcontrollers/health_micro/config`) forces both hand services to
release the old port. So unplug/replug or a port change from the web UI
recovers without restarting the backend.

**Why fail-closed matters**: this machine can also have an ESP32 EMG sensor
plugged in, and the two used to collide. Two symmetric bugs existed before
the rewrite (commit `1f03913`, PR #43):

- Windows: an unmatched search used to `return ports[0].device` — any COM
  port at all, including an empty legacy port or a Bluetooth virtual port.
- Linux: the first sorted `/dev/ttyUSB*` used to win, which can be the ESP32
  instead of the U2D2.

Both were replaced by the VID check above — the only signal that survives
Windows COM enumeration, Linux `ttyUSB*` re-numbering, and driver-text
differences across OSes.

**The mirror-image bug lived on the sensor side**
(`backend/core/serial/manager.py`): `SerialManager.find_device_port()`
excluded the hand's port with `"FTDI" in port.description or "FTDI" in
str(port.hwid)`. Neither field ever contains the string `"FTDI"` — PySerial
reports the U2D2's product string as `"USB <-> Serial Converter"` and its
`hwid` as `USB VID:PID=0403:6014 ...`; only `manufacturer` (never checked)
and the VID identify it. Result: the sensor's autodetect matched the U2D2
first, opened the Dynamixel bus at 921600 bps, and its streaming loop
consumed the motors' replies — current reads failed, torque disabled
fail-closed, the hand stopped moving, and nothing in the error pointed at
the real cause. Fixed the same way: VID first, text fallback second,
`exclude_ftdi=True` by default in `find_device_port()`.

### Per-OS behavior

| OS | U2D2 detection | Latency behavior | Status |
| --- | --- | --- | --- |
| **Windows** (Kevin's laptops) | Same VID/PID `0403:6014` scan through PySerial. No `by-id` path exists on Windows, so `_port_exists()` re-enumerates COM ports instead of using `os.path.exists()`. | The FTDI VCP driver also defaults its **Latency Timer to 16 ms**, set per-port in Device Manager → Ports → *(COM#)* → Advanced. `scripts/doctor.sh` is a Bash script and does not run on Windows. | Detection code is shared with Linux; the latency fix is **manual and has not been measured or automated on this repo** — set it by hand if motion feels sluggish. |
| **Linux (Kevin's laptop, amd64)** | Prefers `/dev/serial/by-id/*FTDI*`, else the VID scan. | `ftdi_sio` defaults `latency_timer` to **16 ms**, serializing every Dynamixel TxRx behind that timer instead of the ~0.2 ms the packet needs at 1 Mbps — measured 15.76 ms/read, 166 ms/11-motor sweep (6.0 Hz ceiling). | Fixed by the udev rule below. |
| **Linux/arm64 (Jetson Nano)** | Identical code path to amd64 — nothing ARM-specific in detection. | Same `ftdi_sio` default, same 16 ms, measured **15.61 ms/read, 164.58 ms/sweep (6.1 Hz)** — statistically identical to the laptop. | Fixed by the same udev rule. |

The Jetson measurement closed the original suspicion that "it doesn't work
on ARM either": it does, identically to x86. The bottleneck is the
`ftdi_sio` driver waiting on its timer, not the CPU computing — ARM changes
nothing about the bus. Where ARM *does* cost real time: the backend test
suite (24.8 s vs 9.4 s on the laptop) and the frontend build (9.7 s vs
6.3 s), both CPU-bound, unlike the bus.

### The latency_timer fix (Linux, amd64 and arm64)

`scripts/99-emgtrainner-u2d2.rules` sets `ATTR{latency_timer}="1"` for any
`ftdi_sio` USB-serial device:

```bash
make install-udev   # requires sudo once; applies live on replug
```

Measured improvement, same bus, same 11 motors (Jetson numbers shown; the
laptop started from the same 16 ms default):

| | latency_timer=16 ms | latency_timer=1 ms | improvement |
| --- | --- | --- | --- |
| READ present_position | 15.61 ms | 2.02 ms | 7.7x |
| WRITE profile_velocity | 16.00 ms | 2.08 ms | 7.7x |
| 11-motor sweep | 164.58 ms → 6.1 Hz | 22.30 ms → **44.8 Hz** | 7.4x |

Zero communication failures at either setting. `make doctor` reports
`[WARN] ttyUSB0 latency_timer = 16 ms (expected 1; run: make install-udev)`
until the rule is applied, then `[OK]`. The 44.8 Hz ceiling is also what
makes issue #44 (webcam teleoperation) viable: below 30 fps was impossible
at 6 Hz.

### Operational gotchas across all three systems

- The backend resolves the hand's port **once, at startup**
  (`EmgService.__init__` → `connect_hand()`). Plugging the U2D2 in after the
  backend is already running leaves `hand_interface = None` with no retry —
  restart the backend process, not just the cable.
- Grant serial access through the `dialout` group on Linux/Jetson, not root:

  ```bash
  sudo usermod -aG dialout $USER
  # log out/in, or use newgrp dialout
  ```

- Prefer a stable path over a raw device name on Linux:

  ```bash
  export DYNAMIXEL_PORT=/dev/serial/by-id/usb-FTDI_...-if00-port0
  ```

- `make doctor` (Linux/macOS only) checks tool versions, FTDI visibility,
  `latency_timer`, and `dialout` membership — all read-only, never opens the
  bus.

## Eleven_DOF_Right mapping

`backend/app/schemas/hand_profiles.py` is authoritative. Other profiles may
map or lock IDs differently.

| ID | Finger | Joint |
| ---: | --- | --- |
| 1 | thumb | `MCP_FE` |
| 2 | thumb | `CMC_AA` |
| 3 | thumb | `CMC_FE` |
| 4 | pinky | `PIP` |
| 5 | pinky | `MCP` |
| 6 | ring | `PIP` |
| 7 | ring | `MCP` |
| 8 | middle | `PIP` |
| 9 | middle | `MCP` |
| 10 | index | `PIP` |
| 11 | index | `MCP` |
| 12–13 | profile-dependent | locked/reserved in supported profiles |
| 14–15 | `Two_Motors` | independently controlled phalanx motors |

The four-finger block was fully reversed relative to the original profile:
the daisy chain runs from the pinky inward, so 4/5 drive the pinky, 6/7 the
ring, 8/9 the middle and 10/11 the index. Every one of those ids was
confirmed on the assembled hand, one motor at a time, with
`python -m tests.hand.identify_motors <id>`. Verify this mapping again on
any rebuilt hand: it reflects the physical daisy chain, not a convention.

## Motion safety contract

- Scan and compare IDs with the selected profile before motion.
- `move_motor_safe` and `move_motors_sync_safe` require three consecutive
  over-limit samples before disabling torque and raising `RuntimeError`.
- Current telemetry fails closed: a read error disables the single motor or
  every synchronized target before raising.
- Overcurrent is a hard stop. Inspect binding, wiring, power and limits before
  retrying; never catch-and-retry it in a loop.
- Inventory never enables torque. Explicit motion/configuration methods do.
- If process state is uncertain, power off the hand before inspection.

## Related

- [Reproducible and recycled environments](reproducible-environment.md)
- [Data governance](data-governance.md)

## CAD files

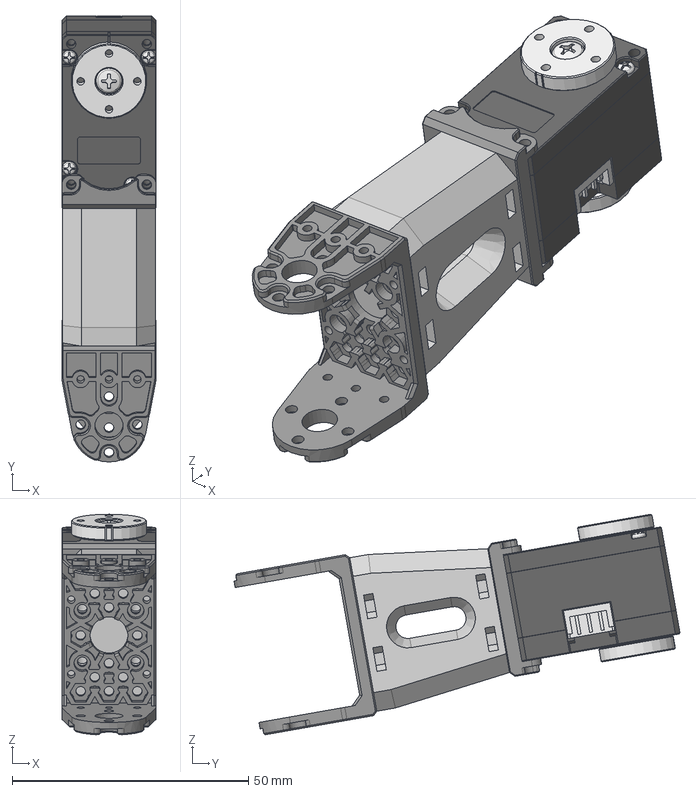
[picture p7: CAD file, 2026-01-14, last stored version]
Componentes_modelo3D/Articulado/Index-IIpp.stp
20.0 x 94.4 x 46.7 mm
DC15_A01_CASE_M_DUMMY
DC15_A01_CASE_F_DUMMY
DC15_A01_CASE_B_DUMMY
DC15_A01_HORN_DUMMY
DC15_A01_LED_CAP2_DUMMY
PHS_1_7X20_5_DC10 x 4
BTS2_M2_6X8 x 2
DC15_A01_HORN_IDLE2_DUMMY
DC15_A01_IDLE_CAP_DUMMY
B3B-EH x 2
fpx330-h101
fpx330-s102
MCP-II

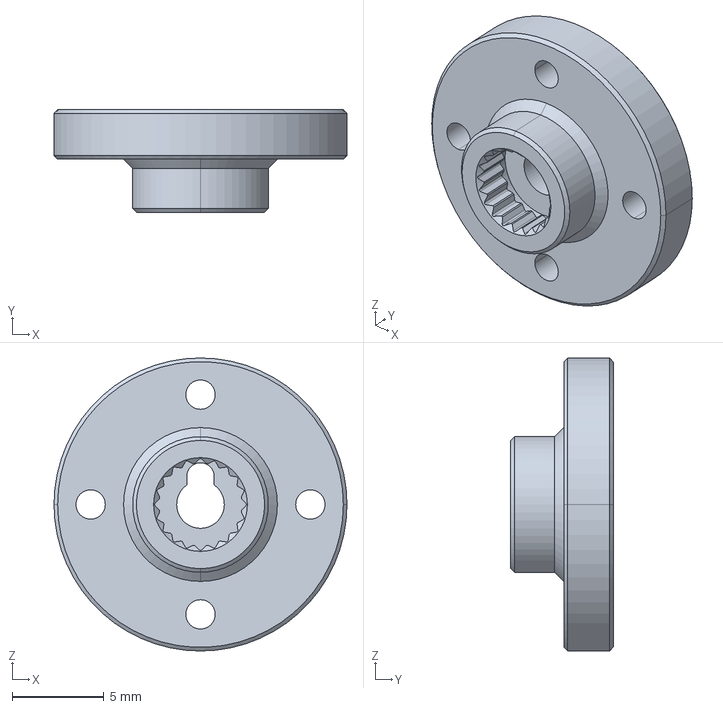
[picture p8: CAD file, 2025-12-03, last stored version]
Componentes_modelo3D/HNX330-N101.stp
16.0 x 5.60 x 16.0 mm

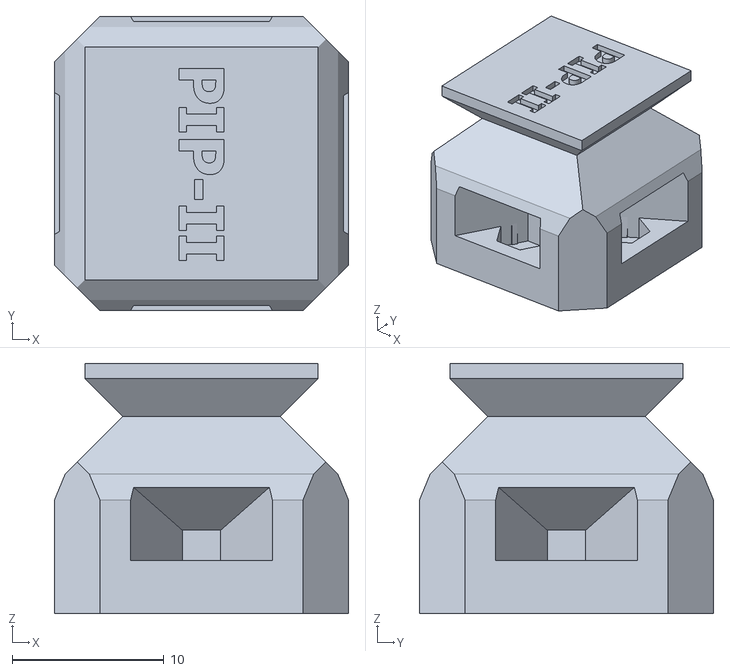
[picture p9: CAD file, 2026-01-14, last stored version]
Componentes_modelo3D/Piezas/STLs/PIP-II_V2.stl
19.4 x 19.4 x 16.5

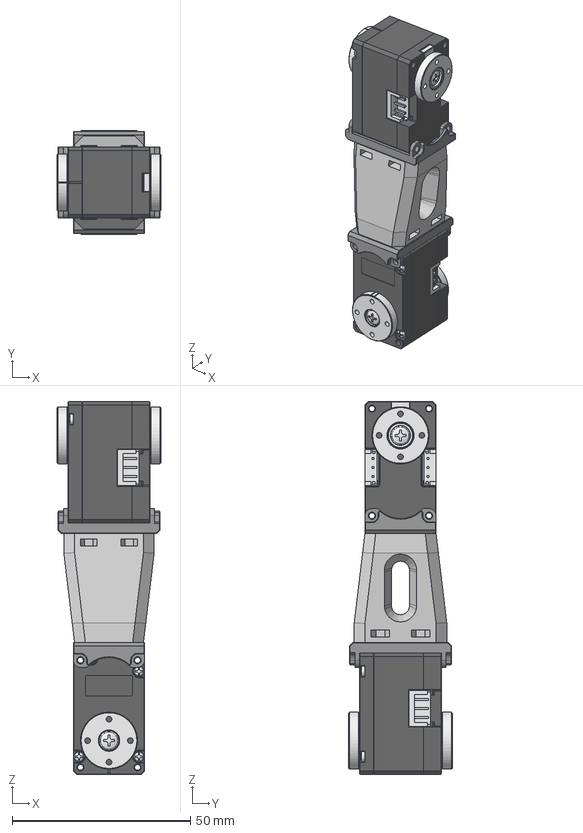
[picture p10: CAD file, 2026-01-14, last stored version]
Componentes_modelo3D/Articulado/Thumb-Im.stp
29.0 x 29.0 x 104.5 mm
DC15_A01_CASE_M_DUMMY x 2
DC15_A01_CASE_F_DUMMY x 2
DC15_A01_CASE_B_DUMMY x 2
DC15_A01_HORN_DUMMY x 2
DC15_A01_LED_CAP2_DUMMY x 2
PHS_1_7X20_5_DC10 x 8
BTS2_M2_6X8 x 4
DC15_A01_HORN_IDLE2_DUMMY x 2
DC15_A01_IDLE_CAP_DUMMY x 2
B3B-EH x 4
fpx330-s102 x 2
MCP-I

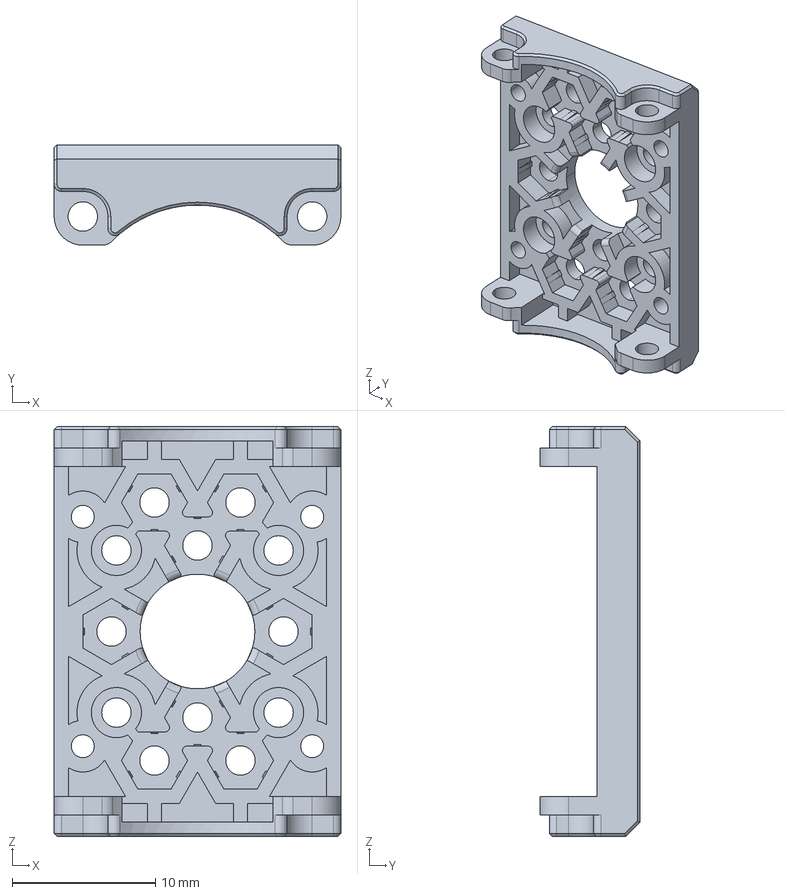
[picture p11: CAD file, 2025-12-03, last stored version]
Componentes_modelo3D/fpx330-s102.stp
20.0 x 7.00 x 28.6 mm

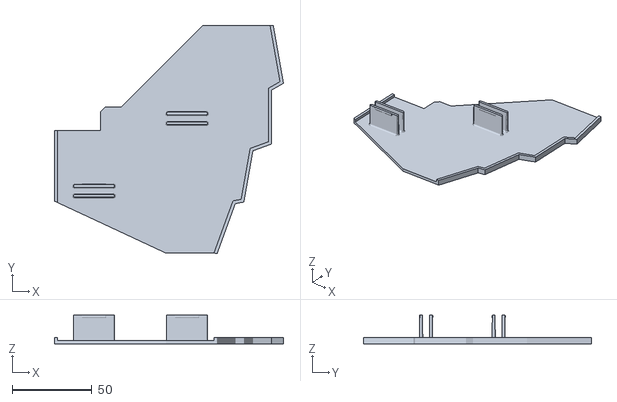
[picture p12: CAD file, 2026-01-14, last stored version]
Componentes_modelo3D/Piezas/STLs/Palmar_Lines-1.stl
143.9 x 143.3 x 18.0

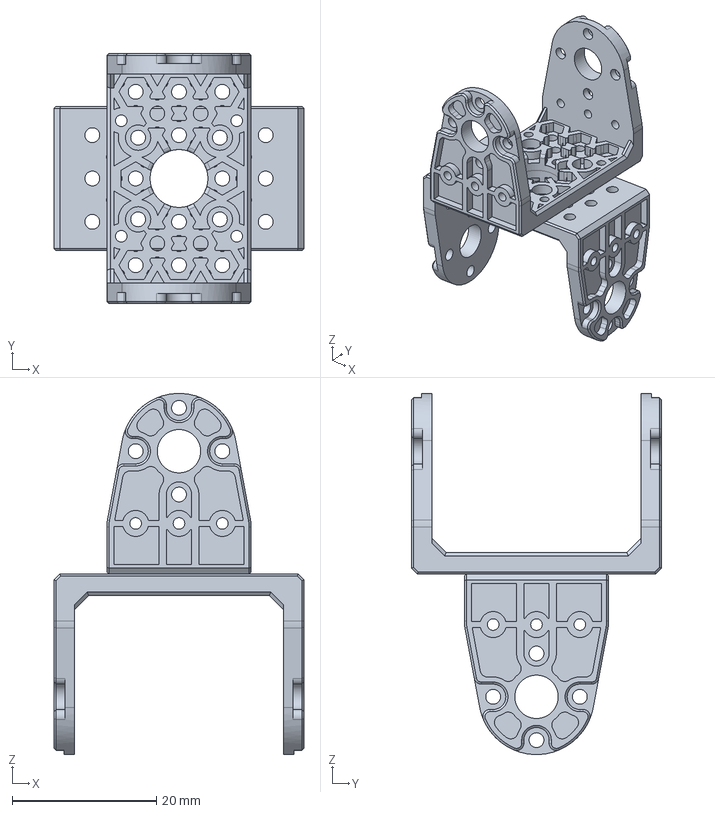
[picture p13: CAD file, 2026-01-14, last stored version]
Componentes_modelo3D/Articulado/Thumb-Ic.stp
34.6 x 34.6 x 50.0 mm
fpx330-h101 x 2

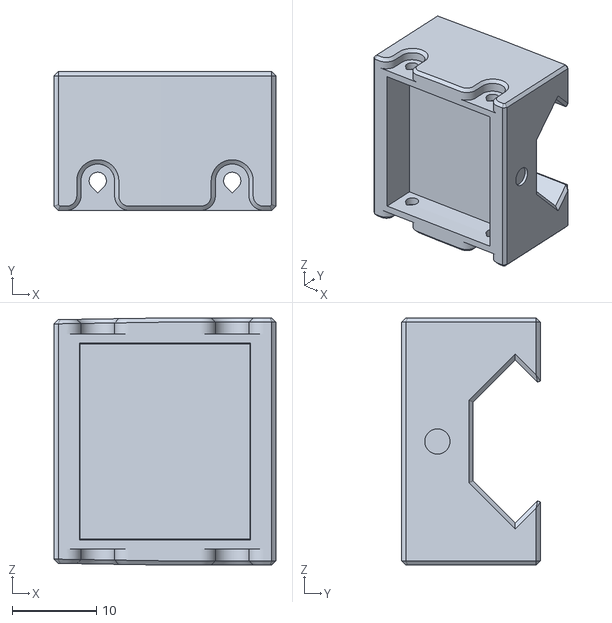
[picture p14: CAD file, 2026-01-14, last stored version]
Componentes_modelo3D/Piezas/STLs/MCP-s102.stl
26.4 x 16.5 x 29.4

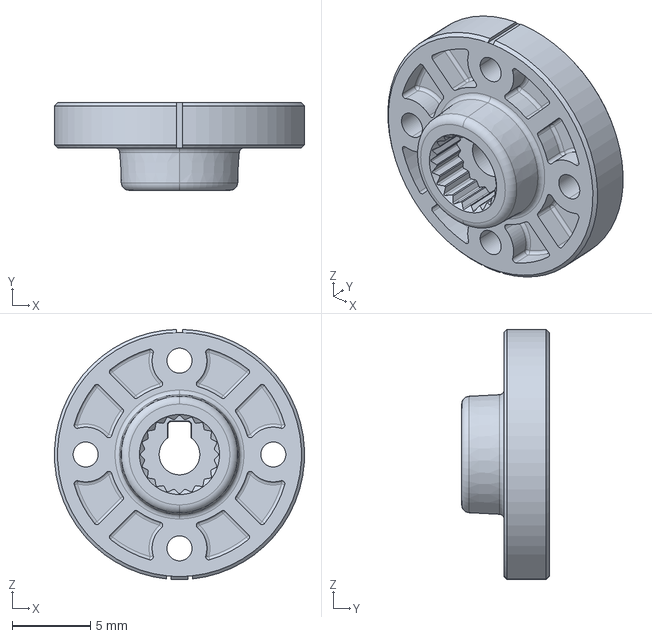
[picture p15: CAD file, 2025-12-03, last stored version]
Componentes_modelo3D/XL_XC_330_HORN.stp
16.0 x 5.60 x 16.0 mm

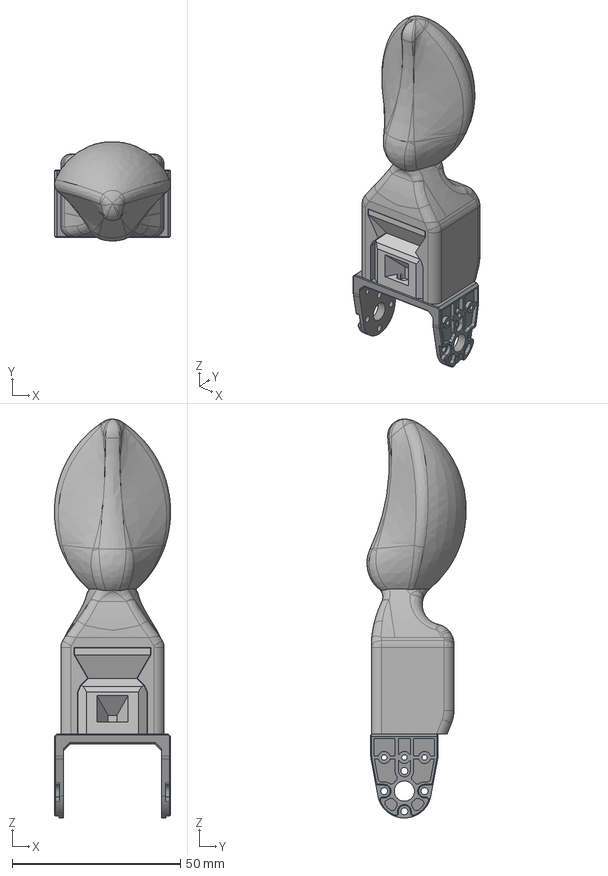
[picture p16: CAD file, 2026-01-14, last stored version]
Componentes_modelo3D/Articulado/Thumb-Id.stp
34.6 x 29.5 x 118.6 mm
DIP-I_V2
PIP-I
fpx330-h101

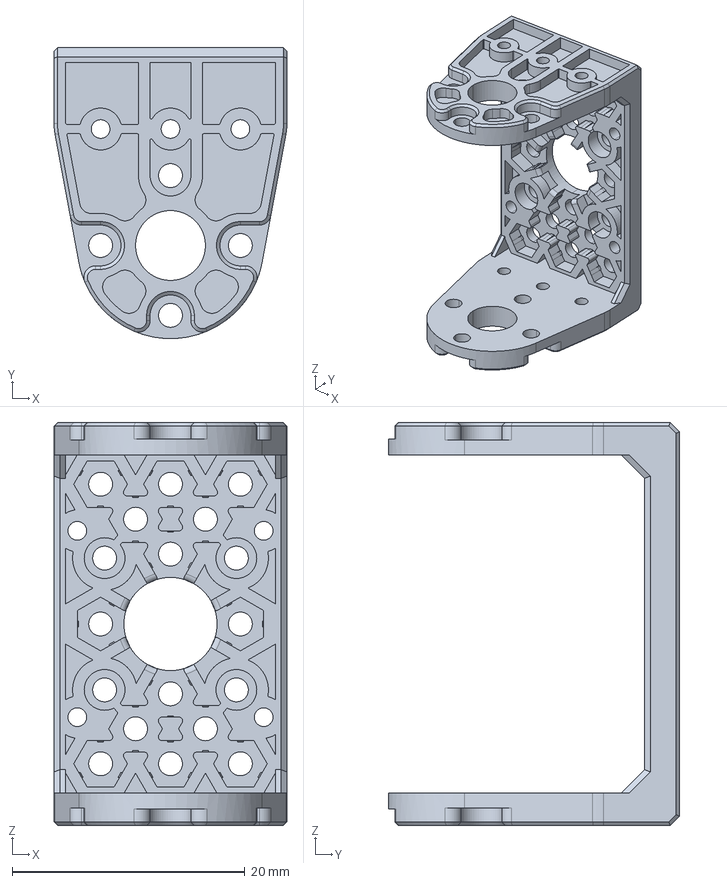
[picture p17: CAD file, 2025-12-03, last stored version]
Componentes_modelo3D/fpx330-h101.stp
20.0 x 25.0 x 34.6 mm

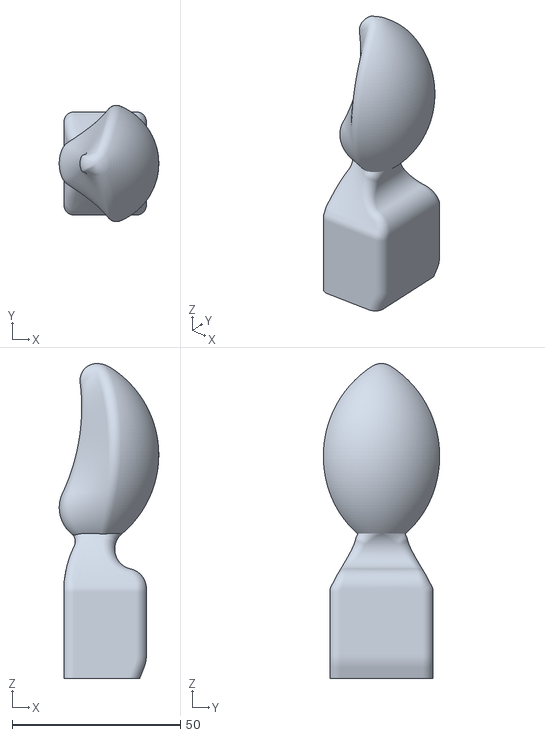
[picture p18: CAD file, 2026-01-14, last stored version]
Componentes_modelo3D/Piezas/STLs/DIP-I_V2.stl
29.6 x 34.6 x 93.6

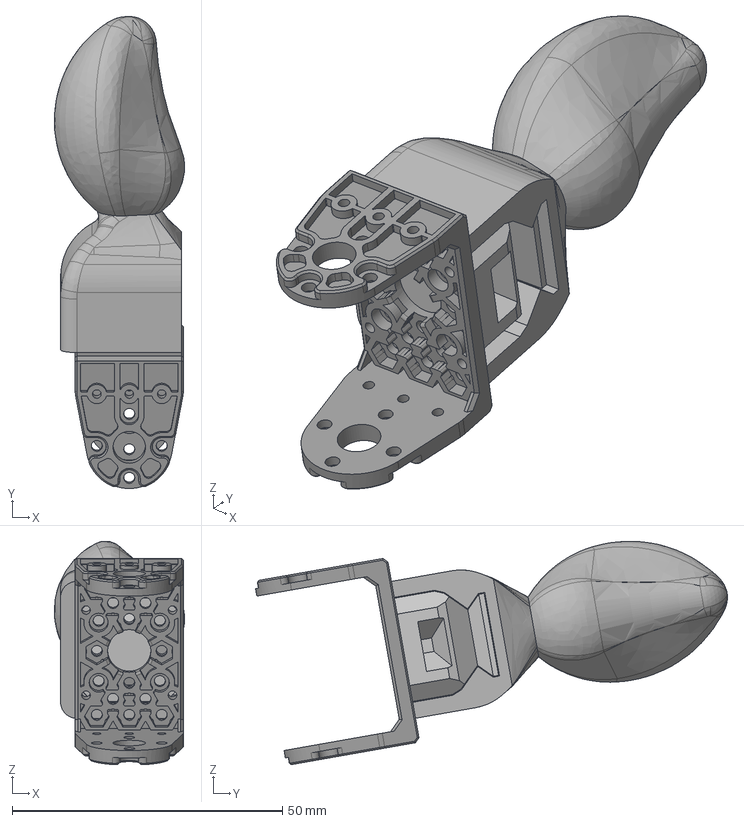
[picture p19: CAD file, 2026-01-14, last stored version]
Componentes_modelo3D/Articulado/Phalanx-dm.stp
24.1 x 87.3 x 41.3 mm
fpx330-h101
DIP-II_V2
PIP-II_V2

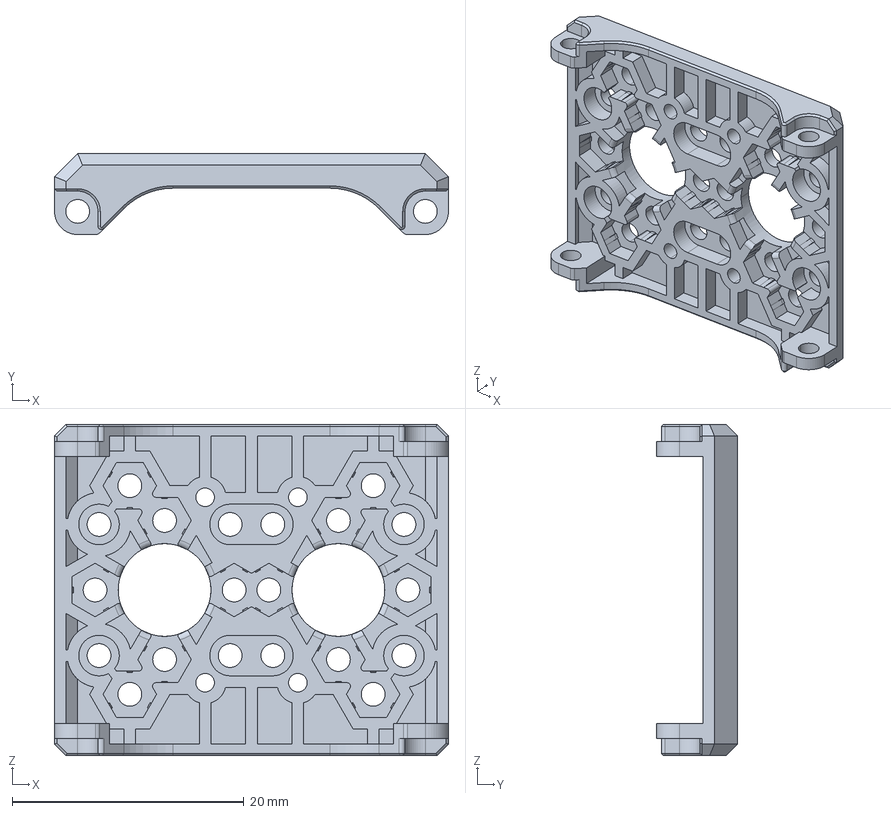
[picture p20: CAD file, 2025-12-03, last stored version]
Componentes_modelo3D/fpx330-s101.stp
34.0 x 7.00 x 28.6 mm

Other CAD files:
Componentes_modelo3D/Piezas/STLs/PIP-I_V2.stl
Componentes_modelo3D/Articulado/Middle-IIIpp.stp
Componentes_modelo3D/fingertip.stl
Componentes_modelo3D/Piezas/STLs/MCP-IV.stl
Componentes/39281023.prt.ipt
Componentes/39281023.stp.iam
Componentes/Board.ipt
Componentes/HNX330-N101.ipt
Componentes/HNX330-N101.stp
Componentes/JST-B3B-EH-A.PRT.1.ipt
Componentes/JST-B3B-EH-A.PRT.ipt
Componentes/JST-B4B-EH-A.PRT.1.ipt
Componentes/JST-B4B-EH-A.PRT.ipt
Componentes/JST-B4B-PH-K-S.PRT.ipt
Componentes/MICRO_USB_2_0_CONNECTOR__AB_REC.PRT.ipt
Componentes/PCB_U2D2.PRT.ipt
Componentes/ROBOTIS_U2D2.iam
Componentes/ROBOTIS_U2D2_Power_Hub_Board.iam
Componentes/ROBOTIS_U2D2_Power_Hub_Board_TOP.iam
Componentes/U2D2.ASM.iam
Componentes/U2D2_CASING.PRT.ipt
Componentes/XL_XC_330_HORN.stp
Componentes/dip.stl
Componentes/fingertip.stl
Componentes/fpx330-h101.ipt
Componentes/fpx330-h101.stp
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

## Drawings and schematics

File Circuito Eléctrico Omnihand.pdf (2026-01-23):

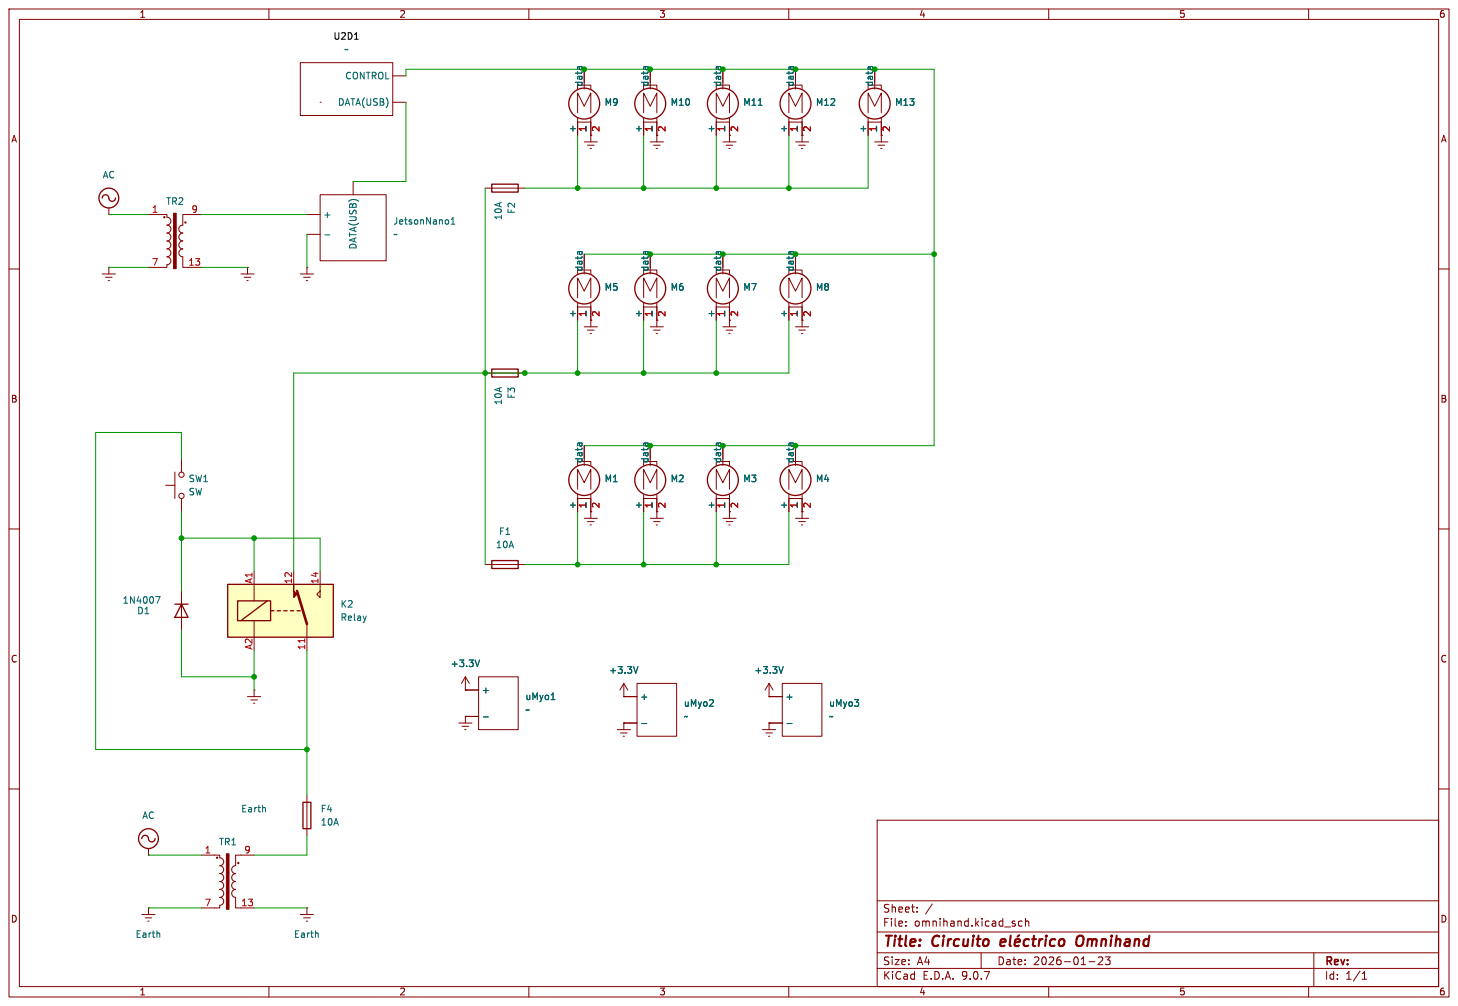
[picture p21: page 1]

File: omnihand.kicad_sch Sheet: /
Id: 1/1 Title: Circuito þÿeléctrico Omnihand

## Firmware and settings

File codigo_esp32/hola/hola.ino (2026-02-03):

/*
Obtaining muscle data from uMyo via BLE on various Arduino boards
Usage: install ArduinoBLE library, run the code on BLE enabled Arduino (nRF52 or ESP32 core)
 - open Serial Plotter (or Serial Monitor) at 115200 speed
 - turn on uMyo device
 - switch it into BLE mode if necessary (to switch, press button once or twice, depending on current mode)
 - you should see muscle activity chart on a plot (or as serial output)
*/

#include <uMyo_BLE.h>

void setup() {
  Serial.begin(115200);
  uMyo.begin();
}

void loop() 
{
  uMyo.run();
  int dev_count = uMyo.getDeviceCount(); //if more than one device is present, show all of them
  for(int d = 0; d < dev_count; d++)
  {
    Serial.print(uMyo.getMuscleLevel(d));
    if(d < dev_count-1) Serial.print(' ');
    else Serial.println();
  }
  delay(30);
}

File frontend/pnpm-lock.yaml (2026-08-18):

lockfileVersion: '9.0'

settings:
  autoInstallPeers: true
  excludeLinksFromLockfile: false

importers:

  .:
    dependencies:
      '@tresjs/cientos':
        specifier: 5.8.1
        version: 5.8.1(@tresjs/core@5.2.1(three@0.180.0)(vue@3.5.26(typescript@6.0.3)))(three@0.180.0)(vue@3.5.26(typescript@6.0.3))
      '@tresjs/core':
        specifier: ^5.0.0
        version: 5.2.1(three@0.180.0)(vue@3.5.26(typescript@6.0.3))
      axios:
        specifier: ^1.13.2
        version: 1.13.3
      lucide-vue-next:
        specifier: ^0.562.0
        version: 0.562.0(vue@3.5.26(typescript@6.0.3))
      pinia:
        specifier: ^3.0.4
        version: 3.0.4(typescript@6.0.3)(vue@3.5.26(typescript@6.0.3))
      three:
        specifier: ^0.180.0
        version: 0.180.0
      three-stdlib:
        specifier: ^2.36.0
        version: 2.36.1(three@0.180.0)
      vue:
        specifier: ^3.5.21
        version: 3.5.26(typescript@6.0.3)
      vue-router:
        specifier: ^4.6.4
        version: 4.6.4(vue@3.5.26(typescript@6.0.3))
    devDependencies:
      '@tresjs/eslint-config':
        specifier: ^1.1.0
        version: 1.5.1(@typescript-eslint/utils@8.52.0(eslint@9.39.2)(typescript@6.0.3))(@vue/compiler-sfc@3.5.26)(eslint@9.39.2)(typescript@6.0.3)
      '@types/estree':
        specifier: ^1.0.9
        version: 1.0.9
      '@types/three':
        specifier: 0.185.0
        version: 0.185.0
      '@vitejs/plugin-vue':
        specifier: 6.0.7
        version: 6.0.7(vite@7.3.1(yaml@2.8.2))(vue@3.5.26(typescript@6.0.3))
      autoprefixer:
        specifier: ^10.4.23
        version: 10.4.23(postcss@8.5.6)
      eslint:
        specifier: ^9.16.0
        version: 9.39.2
      postcss:
        specifier: ^8.5.6
        version: 8.5.6
      tailwindcss:
        specifier: ^4.1.18
        version: 4.1.18
      tailwindcss-animate:
        specifier: ^1.0.7
        version: 1.0.7(tailwindcss@4.1.18)
      typescript:
        specifier: 6.0.3
        version: 6.0.3
      vite:
        specifier: ^7.1.6
        version: 7.3.1(yaml@2.8.2)
      vite-plugin-glsl:
        specifier: ^1.5.1
        version: 1.5.5(esbuild@0.27.2)(vite@7.3.1(yaml@2.8.2))
      vue-tsc:
        specifier: 3.3.6
        version: 3.3.6(typescript@6.0.3)

packages:

  '@antfu/eslint-config@3.6.2':
    resolution: {integrity: sha512-cewFaIEuSSOjbIsNts8gjeMLQrrMDhZjZJHMWk+OyVGJLHRE09JiF5Yg5+XjMVYlG/7fPqeuwEehLrer+8zMfA==}
    hasBin: true
    peerDependencies:
      '@eslint-react/eslint-plugin': ^1.5.8
      '@prettier/plugin-xml': ^3.4.1
      '@unocss/eslint-plugin': '>=0.50.0'
      astro-eslint-parser: ^1.0.2
      eslint: ^9.10.0
      eslint-plugin-astro: ^1.2.0
      eslint-plugin-format: '>=0.1.0'
      eslint-plugin-react-hooks: ^4.6.0
      eslint-plugin-react-refresh: ^0.4.4
      eslint-plugin-solid: ^0.14.3
      eslint-plugin-svelte: '>=2.35.1'
      prettier-plugin-astro: ^0.13.0
      prettier-plugin-slidev: ^1.0.5
      svelte-eslint-parser: '>=0.37.0'
    peerDependenciesMeta:
      '@eslint-react/eslint-plugin':
        optional: true
      '@prettier/plugin-xml':
        optional: true
      '@unocss/eslint-plugin':
        optional: true
      astro-eslint-parser:
        optional: true
      eslint-plugin-astro:
        optional: true
      eslint-plugin-format:
        optional: true
      eslint-plugin-react-hooks:
        optional: true
      eslint-plugin-react-refresh:
        optional: true
      eslint-plugin-solid:
        optional: true
      eslint-plugin-svelte:
        optional: true
      prettier-plugin-astro:
        optional: true
      prettier-plugin-slidev:
        optional: true
      svelte-eslint-parser:
        optional: true

  '@antfu/install-pkg@0.4.1':
    resolution: {integrity: sha512-T7yB5QNG29afhWVkVq7XeIMBa5U/vs9mX69YqayXypPRmYzUmzwnYltplHmPtZ4HPCn+sQKeXW8I47wCbuBOjw==}

  '@antfu/utils@0.7.10':
    resolution: {integrity: sha512-+562v9k4aI80m1+VuMHehNJWLOFjBnXn3tdOitzD0il5b7smkSBal4+a3oKiQTbrwMmN/TBUMDvbdoWDehgOww==}

  '@babel/code-frame@7.27.1':
    resolution: {integrity: sha512-cjQ7ZlQ0Mv3b47hABuTevyTuYN4i+loJKGeV9flcCgIK37cCXRh+L1bd3iBHlynerhQ7BhCkn2BPbQUL+rGqFg==}
    engines: {node: '>=6.9.0'}

  '@babel/helper-string-parser@7.27.1':
    resolution: {integrity: sha512-qMlSxKbpRlAridDExk92nSobyDdpPijUq2DW6oDnUqd0iOGxmQjyqhMIihI9+zv4LPyZdRje2cavWPbCbWm3eA==}
    engines: {node: '>=6.9.0'}

  '@babel/helper-validator-identifier@7.28.5':
    resolution: {integrity: sha512-qSs4ifwzKJSV39ucNjsvc6WVHs6b7S03sOh2OcHF9UHfVPqWWALUsNUVzhSBiItjRZoLHx7nIarVjqKVusUZ1Q==}
    engines: {node: '>=6.9.0'}

  '@babel/parser@7.28.5':
    resolution: {integrity: sha512-KKBU1VGYR7ORr3At5HAtUQ+TV3SzRCXmA/8OdDZiLDBIZxVyzXuztPjfLd3BV1PRAQGCMWWSHYhL0F8d5uHBDQ==}
    engines: {node: '>=6.0.0'}
    hasBin: true

  '@babel/types@7.28.5':
    resolution: {integrity: sha512-qQ5m48eI/MFLQ5PxQj4PFaprjyCTLI37ElWMmNs0K8Lk3dVeOdNpB3ks8jc7yM5CDmVC73eMVk/trk3fgmrUpA==}
    engines: {node: '>=6.9.0'}
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

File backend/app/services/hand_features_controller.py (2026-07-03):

import time
from typing import Dict, List, Optional

from app.utils.motion_math import clamp, deg_to_ticks_xl330, ticks_to_deg_xl330
from app.schemas.hand_features_models import HandProfile, MotorConfig, apply_hand_orientation
from app.services.hand_gesture_library import GESTURES
from app.services.hand_motor_gateway import DynamixelInterface
from app.services.hand_motor_feedback import MotorFeedback


class DynamixelError(Exception):
    pass


class ProstheticController:
    def __init__(self, hand: HandProfile, dxl: DynamixelInterface):
        self.hand = hand
        self.dxl = dxl
        self.last_feedback: Dict[int, MotorFeedback] = {}
        self.max_retries = 3

    def initialize_hand(self):
        for finger in self.hand.fingers.values():
            for motor in finger.motors.values():
                if motor.locked:
                    self.dxl.disable_torque(motor.motor_id)
                else:
                    self.dxl.configure_free_motor(
                        motor.motor_id, motor.max_current_a
                    )

    def validate_gesture(self, name: str) -> bool:
        return name in GESTURES and self.hand.name in GESTURES[name]

    def get_motor_status(self, motor_id: int) -> Optional[MotorFeedback]:
        raw = self.dxl.read_feedback(motor_id)
        if not raw:
            return None

        fb = MotorFeedback(
            motor_id=motor_id,
            position_ticks=raw["position_ticks"],
            position_deg=ticks_to_deg_xl330(raw["position_ticks"]),
            velocity=raw["velocity"],
            load=raw["load"],
            voltage=raw["voltage"],
            temperature=raw["temperature"],
            is_moving=raw["is_moving"],
            error_code=raw["error_code"],
        )
        self.last_feedback[motor_id] = fb
        return fb

    def execute_gesture(self, gesture_name: str) -> bool:
        if not self.validate_gesture(gesture_name):
            return False

        gesture = GESTURES[gesture_name][self.hand.name]

        for finger_name, joints in gesture.items():
            if finger_name not in self.hand.fingers:
                continue

            finger = self.hand.fingers[finger_name]

            for joint, target_deg in joints.items():
                if joint not in finger.motors:
                    continue

                motor: MotorConfig = finger.motors[joint]
                if motor.locked:
                    continue

                angle = apply_hand_orientation(
                    target_deg, motor, self.hand.side
                )
                angle = clamp(angle, motor.min_deg, motor.max_deg)
                ticks = deg_to_ticks_xl330(angle)

                self._move_motor_with_retry(motor.motor_id, ticks)

        return True

    def _move_motor_with_retry(self, motor_id: int, goal_ticks: int):
        for _ in range(self.max_retries):
            try:
                self.dxl.move_motor_safe(motor_id, goal_ticks)
                return
            except Exception:
                time.sleep(0.1)
        raise DynamixelError(f"Motor {motor_id} no respondió")

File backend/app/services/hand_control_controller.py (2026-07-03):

from typing import Dict, List, Tuple

from app.schemas.hand_gestures import GESTURES
from app.schemas.hand_profiles import HandProfile, apply_hand_orientation, MotorConfig
from app.core.dynamixel_interface import DynamixelInterface, DEFAULT_PROFILE_VELOCITY, DEFAULT_PROFILE_ACCELERATION, POSITION_MODE

def initialize_hand_profile(dx: DynamixelInterface, profile: HandProfile):
    for finger in profile.fingers.values():
        for motor in finger.motors.values():
            if motor.locked:
                dx.lock_motor(motor.motor_id, motor.default_deg)
            else:
                dx.configure_free_motor(motor.motor_id, motor.max_current_a)

def _clamp(v: float, vmin: float, vmax: float) -> float:
    return max(vmin, min(vmax, v))

def _collect_targets_for_fingers(dx: DynamixelInterface,profile: HandProfile,gesture: Dict[str, Dict[str, float]],finger_names: List[str],) -> Tuple[Dict[int, int], Dict[int, float]]:
    """
    Retorna:
      targets: {motor_id: goal_ticks}
      current_limits: {motor_id: max_current_a}
    """
    targets: Dict[int, int] = {}
    current_limits: Dict[int, float] = {}

    for finger_name in finger_names:
        if finger_name not in gesture:
            continue
        if finger_name not in profile.fingers:
            continue

        finger = profile.fingers[finger_name]
        joints = gesture[finger_name]

        for joint_name, angle in joints.items():
            if joint_name not in finger.motors:
                continue

            motor: MotorConfig = finger.motors[joint_name]
            if motor.locked:
                continue

            oriented = apply_hand_orientation(angle, motor, profile.side)
            safe_deg = _clamp(oriented, motor.min_deg, motor.max_deg)

            targets[motor.motor_id] = dx.degrees_to_ticks_centered(safe_deg)
            current_limits[motor.motor_id] = motor.max_current_a

    return targets, current_limits

def _configure_motors_before_sync(dx: DynamixelInterface, current_limits: Dict[int, float]) -> None:

    for motor_id, max_a in current_limits.items():
        dx.set_operating_mode(motor_id, POSITION_MODE)

        units = dx.amps_to_current_units(max_a)
        dx.set_current_limit(motor_id, units)

        dx.set_profile_velocity(motor_id, DEFAULT_PROFILE_VELOCITY)
        dx.set_profile_acceleration(motor_id, DEFAULT_PROFILE_ACCELERATION)

        dx.enable_torque(motor_id)

def execute_gesture(dx: DynamixelInterface, profile: HandProfile, gesture_name: str) -> None:
    if gesture_name not in GESTURES:
        raise ValueError(f"[ERROR] - Gesto no definido: {gesture_name}")
    if profile.name not in GESTURES[gesture_name]:
        raise ValueError(
            f"[ERROR] - Gesto '{gesture_name}' no disponible para {profile.name}")

    gesture = GESTURES[gesture_name][profile.name]

      # Caso - Simultaneo
    if gesture_name in profile.all_fingers_simultaneous_gestures:
        finger_list = list(gesture.keys())  # los dedos que existan en ese gesto
        targets, current_limits = _collect_targets_for_fingers(dx, profile, gesture, finger_list)

        _configure_motors_before_sync(dx, current_limits)
        dx.move_motors_sync_safe(targets, timeout_s=1.0, current_limits_a=current_limits)
        return

    # Caso - 4 dedos simultáneo y luego pulgar - grupos definidos en el perfil
    groups = profile.execution_groups or [list(gesture.keys())]

    for group_fingers in groups:
        targets, current_limits = _collect_targets_for_fingers(dx, profile, gesture, group_fingers)

        if not targets:
            continue

        _configure_motors_before_sync(dx, current_limits)
        dx.move_motors_sync_safe(targets, timeout_s=1.0, current_limits_a=current_limits)

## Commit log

2025-11-28 Componentes físicos
    [39281023.prt.ipt, 39281023.stp.iam, Board.ipt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]
2025-12-03 add path route home
    [39281023.prt.ipt, 39281023.stp.iam, Board.ipt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]
2025-12-03 add frontend routes analytics,config-device,patients && layouts
2026-01-12 update patientUI
2026-01-14 Actualización de archivos CAD. Controlador y tester dynamixel
    [39281023.prt.ipt, 39281023.stp.iam, Arm.ipt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]
2026-01-20 Optimización de arquitectura de control DynaHand
2026-01-21 add sensor controller for API
2026-01-21 update details in PatientsFreeSession
2026-01-22 add esp32 code
2026-01-22 más planos de elementos mecánicos
    [DIP-II_V2.idw, DIP-I_V2.idw, Forearm-1.idw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]
2026-01-22 update backend & frontend
    [session_20260122_134447.csv, session_20260122_135453.csv, session_20260122_135907.csv]
2026-01-22 add voices in frontend
    [session_20260122_143916.csv, session_20260122_144202.csv]
2026-01-23 Actualización de información de planos mecánicos
    [DIP-II_V2.idw, DIP-I_V2.idw, Forearm-1.idw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]
2026-01-23 Agregado de marco y cajetín
2026-01-27 implements LLC mode
    [session_20260127_131518.csv]
2026-01-30 replace videos
    [session_20260130_092445.csv]
2026-02-09 add pipline process emg signal
    [session_20260203_161955.csv, session_20260203_162309.csv, session_20260204_111132.csv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]
2026-06-29 refactor(hand): integrate hand module with clean architecture
    - Create HandRequest/HandResponse schemas with Pydantic validation
    - Implement HandService as singleton with hardware dependency injection
    - Add GetHandPosition use case following clean architecture patterns
    - Create RESTful router with GET /hand/position and POST /hand/move endpoints
    - Register hand_router in main.py dependency injection container
    - Remove isolated architecture, unify with project standards
2026-07-03 resolve problems in docker
    [dynamixel_interface.py, hand_control_controller.py, hand_features_controller.py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]
2026-07-06 fix(docker): pin Python version to 3.11.9 for reproducible builds
2026-07-06 feat: migración a SQLite para soporte nativo y configuración de hardware
2026-07-06 fix: apuntar proxy de vite a localhost en lugar de host docker
2026-08-09 chore(data): quarantine private EMG storage
    [Abrir.csv, Apuntar.csv, Cerrar.csv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]
2026-08-09 fix(frontend): plot real emg signal in clinical chart (#30)
    DoctorEMGChart rendered a sinusoid with random noise while labelling
    itself 'Señales sEMG en Tiempo Real' and showing a LIVE badge, so a
    clinician could read simulated data as patient signal. It now renders
    EmgSerialPlotter against the authenticated EMG WebSocket, and the LIVE
    badge follows the real connection state instead of the run flag.
    Device status no longer fabricates a full battery and full WiFi signal;
    those fields pass through the backend payload and are null when absent.
2026-08-09 docs: rewrite readme for emgtrainner (#31)
    The README described a different project: React 19 as the frontend and
    'Prácticas Comunitarias' as the name, with no mention of the sEMG
    pipeline, the hardware, the test suite or the environment contract.
    Replaces it with the real stack (Vue 3 + FastAPI + ESP32), the actual
    run and test commands, the CI jobs, a table of backend environment
    variables, and the security and data-handling boundaries added across
    the remediation phases.
2026-08-18 chore: track the repository quality chain (#39)
    * chore: start repository quality chain
    * fix: make Dynamixel monitoring fail closed (#40)
    * fix: make Dynamixel monitoring fail closed
    * chore: make development toolchain reproducible (#41)
    * chore: make development toolchain reproducible
    * docs: document reproducible EMGTRAINNER setup (#42)
    [dynamixel_interface.py, pnpm-lock.yaml]
2026-08-20 fix(hand): correct the reversed motor-to-finger mapping and record the motion table (#43)
    * fix(hand): correct the reversed motor-to-finger mapping
    The right-hand daisy chain is wired from the pinky inward, so the profile
    mapping was reversed across the whole four-finger block: 4/5 drive the
    pinky, 6/7 the ring, 8/9 the middle and 10/11 the index. Every id was
    confirmed by moving one motor at a time on the assembled hand.
    Only the motor_id values move between fingers. min_deg, max_deg and
    default_deg describe the joint, not the motor, so they stay put - which
    matters in Six_DOF_Right where each finger carries its own defaults.
    Gestures address fingers by name, so GESTURES needs no change.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
    [hand_profiles.py, identify_motors.py]
2026-09-01 fix(hand): stop the EMG sensor from stealing the Dynamixel bus (#45)
    * fix(hand): stop the EMG sensor from stealing the Dynamixel bus
    SerialManager.find_device_port() excluded the U2D2 by checking for the
    literal string "FTDI" in port.description/hwid. Neither field actually
    contains it — PySerial reports the U2D2's product string as "USB <->
    Serial Converter" and its hwid as "USB VID:PID=0403:6014 ...". Only
    manufacturer (never checked) and the vendor id identify it.
    Result: the EMG sensor's autodetect matched the U2D2 first, opened the
    Dynamixel bus at 921600 bps, and its streaming loop consumed the
    motors' replies. Current reads failed, torque disabled fail-closed,
    and the hand stoppe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
    [manager.py, test_sensor_port_discovery.py]
2026-09-01 fix(patients): wire the patient list and supervised session to real data (#46)
    * fix(patients): commit patient creation so it actually persists
    PatientController.create_patient was the only create-path in the repo
    without @Transactional. AuthController.register and TaskController.add
    both commit after the repository call; this one didn't, so the
    session never flushed and:
    - the response serializer raised ResponseValidationError (500): id,
    sessions_count, progress, created_at and updated_at were all still
    None on the in-memory object;
    - worse, nothing was actually written to the database — the row was
    silently discarded when the request's scoped session closed.
    Verified end-to-end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
2026-09-01 fix(hand): validate the configured serial port before trusting it (#47)
    * fix(hand): validate the configured serial port before trusting it
    find_u2d2_port returned hardware_config.main_port and DYNAMIXEL_PORT
    without checking either existed. A Jetson carrying a stale
    main_port=/dev/ttyUSB1 while the adapter sat on ttyUSB0 failed with a bare
    open() error and no hint that autodetection was available.
    Autodetection now identifies the adapter by FTDI vendor id 0x0403 on every
    platform, keeping the stable by-id symlink as the Linux preference. arm64
    and amd64 share that path; Windows validates COM names through port
    enumeration, since they are not filesystem paths.
    Removes two blind fallbacks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
    [dynamixel_interface.py]
2026-09-15 fix(hand): recover the Dynamixel bus when the U2D2 is replugged (#48)
    The backend resolved the hand port exactly once: unplugging and
    replugging the U2D2 (possibly as a different /dev/ttyUSBn) left every
    gesture from the web UI silently dropped or written to a stale handle
    until the backend was restarted.
    - EMGDataService retries connect_hand() lazily on the next gesture when
    the interface is missing, and drops the handle after a transport-level
    failure so the next gesture re-resolves the port.
    - POST /v1/microcontrollers/health_micro/config now forces both hand
    services to release the old port, so the frontend's USB config module
    takes effect immediately without a restart.
    - Dynami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
    [dynamixel_interface.py]
2026-11-01 Pr/09 integracion (#58)
    * Roles, autenticación y usuarios: acceso por rol, seeds de doctores y pruebas
    * UI del doctor: sesión en vivo, alertas y gráfico EMG
    * Hardware: interfaz Dynamixel, gestor serial y modal de dispositivos
    * Señal EMG: limpieza, estudio de calibración, registro de movimiento libre y pruebas
    * Clasificador de gestos: características, clasificador, reconocimiento y scripts
    * UI del paciente: vistas de movimiento libre y sesión supervisada
    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
2026-11-01 Pr/08 firmware esp32 (#57)
    * Modo espejo: reflejo de la mano en tiempo real, calibración y E-stop en el frontend
    * Firmware ESP32: puente uMyo, diagnóstico y firmware principal
    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
2026-11-01 Roles, autenticación y usuarios: acceso por rol, seeds de doctores y pruebas (#50)
2026-11-01 Pr/02 UI doctor (#51)
    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
2026-11-01 Pr/03 hardware (#52)
    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
2026-11-01 Pr/04 senal emg (#53)
    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
2026-11-01 Pr/05 clasificador gestos (#54)
    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
2026-11-01 Pr/06 UI paciente sesiones (#55)
    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
2026-11-01 Pr/07 modo espejo (#56)
    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
